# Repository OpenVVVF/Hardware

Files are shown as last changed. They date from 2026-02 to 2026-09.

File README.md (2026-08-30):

# OpenVVVF Hardware

> This repository contains the **OpenVVVF Hardware** designs. User-facing documentation, safety analyses, assembly guides, and test evidence now live in [OpenVVVF/Documentation](https://github.com/openvvvf/documentation) (rendered at https://docs.openvvvf.org/). The matching firmware, Real Time Examiner (RTE) host tool, and supporting configuration utilities (including node codegen and telemetry tooling) now live in [OpenVVVF/RTE](https://github.com/OpenVVVF/RTE).

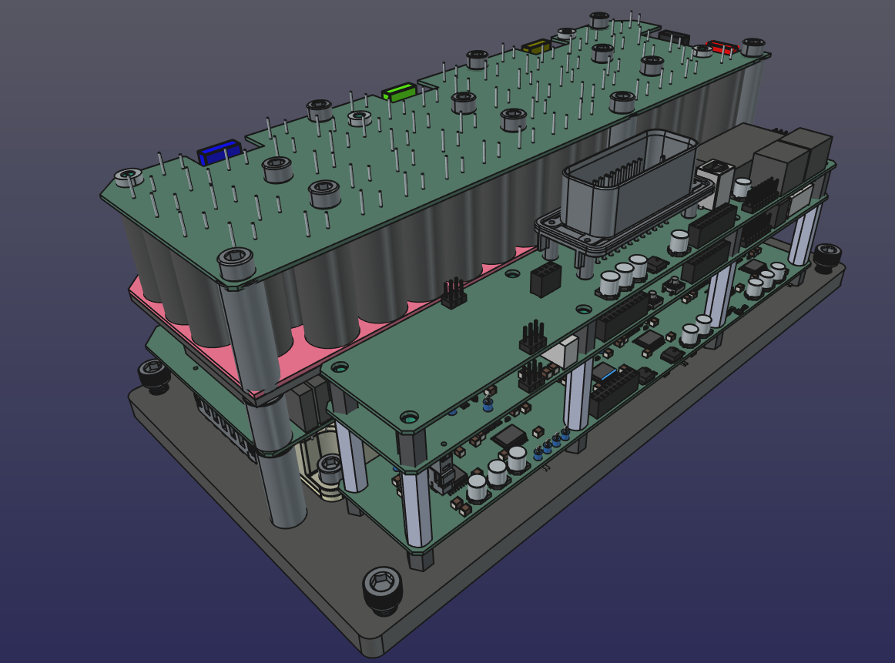
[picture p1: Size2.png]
Size 2 Inverter CAD Rendering


*Our current in-progress build photos for size 2 are below, thanks again to our sponsors for helping make this possible*
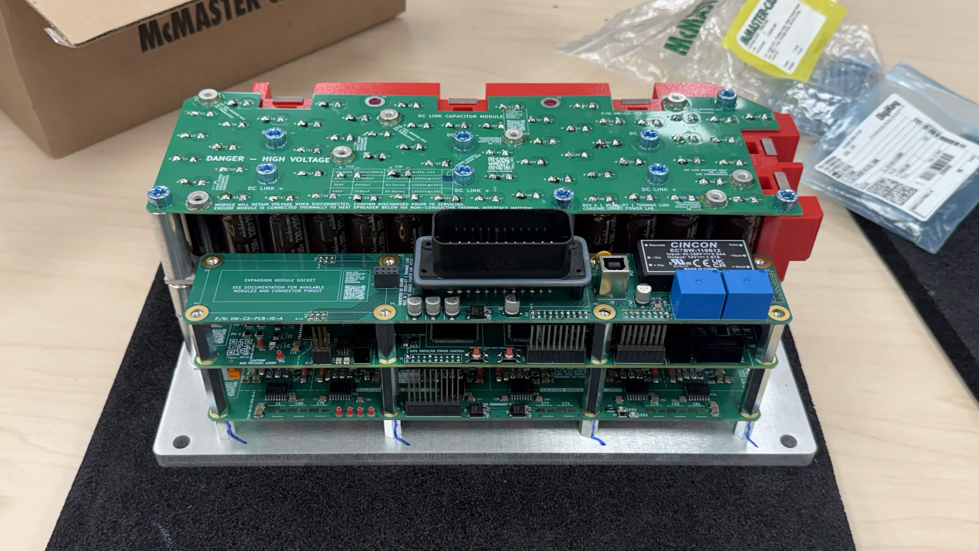
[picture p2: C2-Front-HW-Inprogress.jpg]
Size 2 Inverter Physical Assembly In-Progress

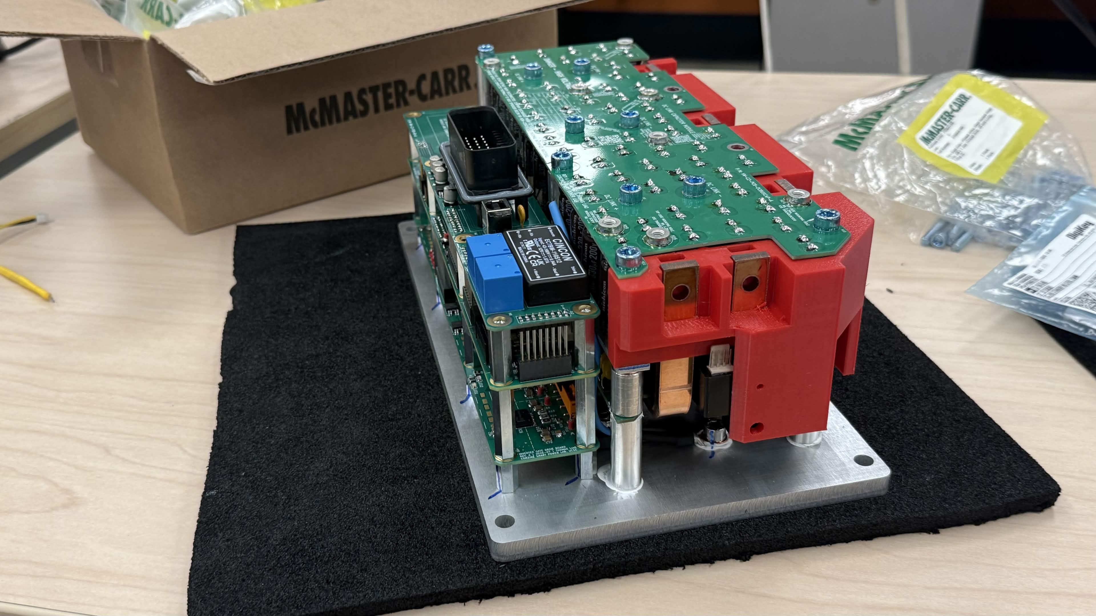
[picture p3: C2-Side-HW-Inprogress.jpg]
Size 2 Inverter Physical Assembly In-Progress


An open-source, high-power voltage-source inverter (VSI) for 3-phase AC drives. The design centres on a dual-MCU control board with an independent safety coprocessor, fully isolated gate drives and sensing, dual isolated CAN buses, and a control stack configurable through node-based codegen tools.

> **A note on the name:** *VVVF* stands for Variable Voltage Variable Frequency — it describes the output, not the control strategy. This platform is **not** limited to scalar V/Hz control; it supports vector control (FOC), arbitrary modulation schemes, and any control scheme you can express through the node-based codegen tools.

The present hardware implementation (Chassis Size 2) is a 200–450 V class build rated **465 A continuous / 600 A peak for 60 s** (IEC 61800-2 style overload convention; peak phase current figures — 330 A / 424 A RMS). The usable DC bus voltage is set by the installed DC link capacitors: 200 V class with the stock 200 V aluminium-electrolytic bank, or up to 450 V class with a capacitor-only swap to 450 V parts. The platform is designed to scale to higher voltage and current classes with appropriate gate-driver, DC link, and sensing-divider adaptations.

This project is currently being developed in Dr. Keith Corzine's Smart Power Lab at the University of California, Santa Cruz.

The hardware designs are modular and share a common control architecture and communication interfaces with the firmware in [OpenVVVF/RTE](https://github.com/OpenVVVF/RTE). All hardware and software are released under open-source licenses.

## Platform Scalability

The control board is designed as a reusable platform that is largely independent of the power stage. With isolation barriers rated for high-voltage power stages (CAN transceiver VIORM 2121 V<sub>PK</sub>; voltage-sense range 1.8 kV full-scale), the same inverter can be paired with a wide range of inverter classes; higher voltage classes are achievable with straightforward gate-driver and sensing-divider adaptations. The PWM and protection interfaces are also compatible with user-supplied gate-drive stages, allowing the inverter to be integrated into custom power-converter designs. Planned chassis variants include:

| Variant | Voltage Class | Phase Current | Status |
|---|---|---|---|
| Chassis Size 2 | 200 V class (stock 200 V capacitors); 450 V class (450 V capacitor swap) | 465 A continuous / 600 A peak, 60 s | Implemented, under test |
| Chassis Size 2 DC/DC module (C2-DCDC-A) | 450 V class | 15 kW DC/DC converter | Released (orderable BOMs) |
| Chassis Size 3 | Up to 1200 V (capacitor-dependent) | 1400 A | In development |

The **Chassis Size 2 DC/DC module** (release tag `C2-DCDC-A`) reuses the Chassis Size 2 PCBs and power stage as a 15 kW DC/DC converter for microgrid applications, built in the 450 V capacitor class. On top of the base machine it adds a pair of Hammond 195C100 DC filter chokes (1 mH, 100 A), two Boyd 416201U00000G 305 mm 6-pass cold plates, a TDK B25645A1328K003 3.21 mF/1 kV DC-link film capacitor, and a sheet-metal frame/cabinet set (base plates, cornerposts, cover lids, coldplate holder). The assembly model is `Hardware/Chassis2/Mechanical/DC-DC-Module.FCStd` (exported as `DC-DC-Module.step.gz`); the orderable BOMs, pricing report, and fab files are generated by the BOM tool as the `dcdc` build variant under `Hardware/Chassis2/FabricationData/Builds/dcdc/`.

Semiconductor ratings are selected with margin for the target DC bus: Chassis Size 2 uses 600 V rated IGBTs for the 200–450 V range, while future higher-voltage classes use 1200 V or 1700 V rated parts as appropriate.

## Hardware Architecture

### Power Stage
- **3-phase 2-level IGBT bridge** built from three Mitsubishi CM600DY half-bridge modules (six switches, 600 A class, 62 mm package). The recommended device for Chassis Size 2 is the **CM600DY-13T** (600 V), which matches the 200–450 V DC bus range. The **CM600DY-24T** (1200 V) is also electrically and mechanically compatible and may be used if a higher-voltage device is preferred.
- **Phase current**: 465 A continuous / 600 A peak for 60 s (peak phase current; 330 A / 424 A RMS) — continuous is a conservative analytical bound set by the DC-link electrolytic ripple rating at 6 kHz PWM (full-load dyno validation pending); peak duty is windowed: rolling 10-min RMS ≤ 330 A RMS
- **DC bus voltage**: 200–450 V class, set by the installed DC link capacitors — 200 V class with the stock bank, up to 450 V class with a capacitor-only swap (see DC Link below)
- **Gate drivers**: Six onsemi NCV57100 isolated IGBT gate drivers (one per switch, AEC-Q100 automotive-qualified)
  - Reinforced isolation: >5 kV<sub>rms</sub> (UL1577), 1424 V<sub>PK</sub> / 1000 V<sub>rms</sub> working voltage (VDE 0884-11)
  - DESAT short-circuit detection (1200 V fast-recovery diode + blanking) with soft turn-off
  - Separate OUTH/OUTL gate outputs; active Miller clamp connected directly to the gate
  - Complementary IN+/IN&minus; inputs cross-wired between the high- and low-side switches of each leg — hardware shoot-through lockout
  - All six ~FLT outputs wired-OR into a single FAULT net (&rarr; TIM1_BKIN); all six ~RDY wired-OR into a READY net; common DRIVER_RESET line
- **Gate drive power**: Six Murata MGJ2D121509MPC-R7 isolated DC/DC converters
  - 12 V input &rarr; isolated +15 V / &minus;9 V bipolar output per gate driver
  - Each supply fully isolated from logic and from each other
  - **1oo2 power kill**: the common 12 V feed passes through two series-connected BTS462T smart high-side switches — one controlled by the main MCU (GATE_DRIVE_PWR1_ENABLE), one by the coprocessor (GATE_DRIVE_PWR2_ENABLE). Either switch opening removes power from all six supplies simultaneously, forcing all IGBT gates off as the driver rails collapse into UVLO (gates discharge via the OUTL/Miller-clamp path). Resistor-divider feedback from both switch nodes (GATE_DRIVE_PWR1_FB / GATE_DRIVE_PWR2_FB) lets each MCU verify the other's path.
- **Power-stage agnostic control board**: The same inverter and firmware can be paired with alternative power stages with only gate-driver and sensing-divider scaling; higher voltage classes are achievable with straightforward adaptations, or the board can be interfaced to a user-supplied gate-drive stage.

### DC Link
- **Capacitor bank (current build)**: 60&times; Nichicon UCS2D331MHD 330 &micro;F / 200 V aluminium electrolytics in parallel &rarr; 19.8 mF total, 200 V class. The 450 V capacitor-only upgrade is a single part-number swap to 60&times; Nichicon UCS2W680MHD 68 &micro;F / 450 V parts (4.08 mF total); the only mechanical change is 5 mm shorter standoffs (e.g., 55 mm &rarr; 50 mm) to match the shorter capacitors. This is what gives Chassis Size 2 its 200–450 V class range.
- **Filter board**: 6&times; 10 &micro;F / 1000 V metallized polypropylene film capacitors (absorb high-frequency ripple and clamp switching voltage spikes, reducing RMS ripple current in the electrolytics) + 12&times; 0.25 &micro;F / 900 V TDK CeraLink low-inductance ceramics at the module terminals + 18&times; 2.2 nF class-Y safety capacitors to chassis for common-mode / bearing-current (EDM) suppression
- **Busbar-style construction**: all power connections are M6 bolted mounting holes; the mounting hardware sits at bus potential — observe high-voltage precautions during assembly
- **No onboard bleeder**: the bank has no discharge resistor and remains at bus voltage for hours after power-down (discharge only via M&Omega;-scale parasitic paths). Verify bus voltage with a meter and discharge through a power resistor before any service.
- **Capacitor cooling**: the capacitor bank is thermally coupled to a 6.35 mm (1/4 in) aluminium heat-spreader plate (rev B; thickened from 3.18 mm rev A), itself mounted to the heatsink via six 63 mm aluminium standoffs (13 mm OD, three go-return pairs in parallel - the rods also carry the DC-link current between the film board and the capacitor bank). The thermal path is sized for a 40 W ripple-current heat load: ~35 &deg;C total temperature rise with thermal paste (&asymp;75 &deg;C plate temperature at a 40 &deg;C heatsink base). Full analysis: [DC Link Thermal Analysis](https://openvvvf.github.io/Documentation/Power-Stages/C2/Design-Documents/DC-Link-Thermal/index.html) in OpenVVVF/Documentation. Use aluminium standoffs only — steel is not acceptable in this thermal path.
- **Precharge**: onboard high-side relay on the IO board with a user-supplied external resistor — size the resistor so precharge current stays below 2 A (input fuse limit)

### Current Sensing
- **Four Tamura LA37S600S05KM hall-effect current transducers** (3 phase + DC link)
  - &plusmn;1200 A sensing range, centered at 2.5 V output
  - Separate reference signal per sensor for fault detection
  - ~70 mA/LSB quantization at 16-bit (&asymp;300 mA effective resolution after oversampling/decimation); overall accuracy is dominated by the sensor's &plusmn;1.8% specification
  - Analog ground kept separate and bonded at the STM32 for noise reduction

### Voltage Sensing
- **MAX22530AWE+ 12-bit isolated ADC** with 4 channels
  - Measures DC bus voltage and all three phase voltages (U, V, W)
  - 1001:1 high-voltage divider per channel (4&times; 250 k&Omega; nominal series + 1 k&Omega; shunt, zener-clamped) &rarr; measurable range to ~1.8 kV full-scale, ~0.44 V/LSB referred to the bus (continuous bus limited to ~800 V by the fitted divider resistors; higher-voltage builds need HV-rated divider parts)
  - ~&plusmn;1 V measurement accuracy at the 140 V build with calibration (divider tolerance dominates at higher bus voltages)
  - SPI interface to STM32; isolation provided by the ADC's internal reinforced barrier

### Communication
- **Dual isolated CAN bus**: ISO1042BDWVR isolated CAN FD transceivers (70 V bus fault protection)
  - Two transceivers per bus (four total): the main MCU and the safety coprocessor each have an independent, galvanically isolated transceiver on both buses, so the coprocessor can snoop and cross-check all bus traffic
  - Per-bus isolated 5 V supply with firmware-switchable power; jumper-selectable 120 &Omega; termination
  - CAN1: Battery Management System (BMS) and IO board harness
  - CAN2: display/dash, charger(s), diagnostic tools
- **Expansion module connector (J2, IO board)**: plug-in expansion header carrying MD_FIBER_TX/RX/SYNC, +5 V, +12 V, and GND for future add-on modules. Planned modules include:
  - **Fiber IO multidrive module** — distributed-drive coordination for 5+ phase motors, parallel power stages with current sharing and load balancing, or tightly synchronized multi-drive systems with hardware PWM sync between drives
  - **Fiber-optic gate-drive module** — isolated PWM signaling directly to gate drivers
  - **WiFi/Bluetooth module** — wireless telemetry and configuration
  - **Resolver interface module** — resolver position feedback (native inputs support sin/cos encoder or Hall effect only)
- **BMS heartbeat**: 5-second timeout (HARA FSR-17; BMS external to this system; firmware implementation in progress)

### Control Electronics — Dual-MCU Architecture
- **STM32H723ZG** main MCU (550 MHz Cortex-M7)
  - ECC-protected RAM, 1 MB flash
  - FDCAN1 + FDCAN2, TIM1 advanced-control PWM, 16-bit ADCs
  - Runs FOC motor control, sensor acquisition, CAN communication, safe state management
  - GATE_DRIVE_PWR1_ENABLE — gate drive power kill Path 2a
  - CY15B102Q-SXET 256 KB SPI FRAM (GPIO-controlled write-protect) for fault logs, configuration, hour meter, odometer
- **STM32G474RCTx** safety coprocessor (170 MHz Cortex-M4+FPU)
  - 8 MHz crystal; powered from the shared 3.3 V rail (dedicated RD7-12S033R DC/DC converter)
  - FDCAN2 + FDCAN3 (independent transceivers on both CAN buses for snooping/cross-check)
  - Independent ADC access to all current sensors, temperatures, encoder, gate drive feedback
  - Monitors all 6 PWM output pairs (high/low) for deadtime violations, stuck-on, stuck-off
  - GATE_DRIVE_PWR2_ENABLE — gate drive power kill Path 2b (1oo2 with main MCU)
  - Challenge-response watchdog with main MCU via inter-MCU UART
  - Bidirectional NRST and mutual BOOT0 control — either MCU can reset or bootloader-force the other; own SWD and native USB debug ports
- **Rail supervision**: TI TPS389006-Q1 6-channel window supervisor with I2C-programmable thresholds (TI Functional Safety-Compliant component, supporting designs up to SIL 3 / ASIL D per TI)
  - Monitors the 3.3 V, 5 V, 12 V, and sensor 5 V rails plus both gate-drive power feedbacks; thresholds are I2C-configured by the main MCU at boot
  - On any rail fault — including brownout of the 3.3 V rail shared by both MCUs — it asserts DRIVER_RESET **directly**, forcing all NCV57100 outputs off while bypassing both MCUs. The actuation path is hardware-only: an independent mitigation for the shared-rail common-cause failure mode
- **Isolated digital inputs**: 8&times; ISO1212 24&ndash;60 V isolated input channels (2 populated in the current build, routed to the coprocessor) for e-stop, limit switches, and user inputs
- **Onboard power**: Cincon EC7BW-110S12 railway-grade DC/DC (mounted on the IO board, powered from the traction battery)
  - 43&ndash;160 V input (4:1), 12 V / 1.67 A output
  - EN 50155 compliant with external circuitry (per Cincon application note), 1500 V I/O isolation
  - Control-board rails derived from 12 V: 3.3 V (RD7-12S033R), isolated 5 V (RKE-1205S), firmware-switched 12 V aux and CAN-bus power (BTS462T high-side switches)
- **Fail-safe default**: Six-switch-open (SSO) &mdash; all IGBTs off

### Throttle Input
- Dual redundant 5 k&Omega; potentiometers + end-travel limit switch (via isolated digital input)
- 0&ndash;5 V output scaled to 0&ndash;3.3 V via resistor dividers
- Both MCUs read throttle independently; discrepancy &gt;5% triggers safe state

### Safe State Entry — Six Redundant SSO Pathways

1. **TIM1_BKIN hardware break input to main MCU** (<100 ns) — OR'd gate driver FLT → hardware clears MOE, all PWM disabled
2. **Coprocessor reset to main MCU via NRST** (~100 ms) — challenge/response failure → coprocessor resets main MCU → SSO during boot
3. **Loss of shared 3.3 V rail (passive)** — NCV57100 VDD lost → internal active pull-down → SSO; no software intervention
4. **Gate driver RESET line** (<1 us actuation once asserted, either MCU or the TPS389006-Q1 rail supervisor) — asserts DRIVER_RESET → all NCV57100 outputs off → SSO
5. **1oo2 gate-drive power disable** — main MCU (`GATE_DRIVE_PWR1_ENABLE`) or coprocessor (`GATE_DRIVE_PWR2_ENABLE`) opens its BTS462T; either alone removes 12 V → gate-drive UVLO → SSO. Feedbacks: `GATE_DRIVE_PWR1_FB`, `GATE_DRIVE_PWR2_FB`
6. **Coprocessor independent fault trigger** (<10 us) — coprocessor detects critical fault → `GATE_DRIVE_PWR2_ENABLE` low + RESET → SSO without main MCU

> **Note:** HARA v4.1 numbers these as Path 1, Path 5, Path 3, Path 4, Paths 2a/2b, and Path 6, respectively. The TPS389006-Q1 rail supervisor is an additional actuator on the RESET pathway (Path 4), not a separate SSO path.

### Safety Protections (Hardware + Dual-MCU)

*Hardware for all mechanisms below is in place; firmware implementation of several monitors is in progress (see Project Status).*

- Hardware PWM disable via TIM1_BKIN (&lt;100 ns)
- NCV57100 DESAT short-circuit protection (&lt;2 us)
- 1oo2 gate drive power kill with independent feedback (GATE_DRIVE_PWR1_FB, GATE_DRIVE_PWR2_FB)
- TPS389006-Q1 rail supervisor (Functional Safety-Compliant, up to SIL 3 / ASIL D per TI) — resets the gate drivers directly on brownout, independent of both MCUs
- Dual independent watchdog timers (main MCU windowed WDT + coprocessor challenge/response)
- HVIL (High-Voltage Interlock Loop) presence signalling &mdash; planned (TODO on IO board schematic)
- All six NCV57100 FLT outputs OR'd — monitored by **both** MCUs
- Overcurrent detection: ADC analog watchdogs in both MCUs (hardware threshold monitoring, no external comparators) + dual-MCU integrated monitoring — detection within 100 ms for regular overcurrent; SSO assertion within 1 PWM period (~100 µs) once detected — sufficient for safe torque off without hardware damage (DESAT handles hard shorts &lt;2 us) + Analog watchdog on main processor and coprocessor for overcurrent.
- **Target: ASIL D** via ASIL B(D) + ASIL B(D) decomposition (DFA per ISO 26262-9 pending — LIMIT-08)

> **Note on Overcurrent Protection:** Hardware overcurrent detection uses the ADC analog watchdogs built into both STM32s — comparator-equivalent threshold monitoring on each current channel with no external components. The control board also includes schematic provision for LM397 comparators for phase and DC link overcurrent detection, but these are not populated in the current build and are not required for the safety case. Hard short-circuits are handled by NCV57100 DESAT (&lt;2 us). Regular overcurrent (non-DESAT) is detected within **100 ms** by dual-MCU integrated monitoring and AWD — both the STM32H723 and STM32G474 independently sample all current channels at high rate. Once detected, either MCU asserts SSO within **1 PWM period (~100 µs)** via its independent gate drive power kill — the full sense-to-safe-off path. The 100 ms detection latency is faster than the IGBT thermal time constant; junction temperature remains within module ratings for overloads sustained up to the 100 ms detection bound. The LM397 provision is retained in schematic, and may be removed in future versions pending testing and validation of current design.

## Motor Control

Field-Oriented Control (FOC) running at PWM switching frequency with the following modulation strategies:
- **SPWM** &mdash; Sinusoidal Pulse Width Modulation
- **SVPWM** &mdash; Space Vector Modulation
- **ARSVPWM** &mdash; Alternating Reverse Sequence Vector PWM
- **SHEPWM** &mdash; Selective Harmonic Elimination
- **RCFM** &mdash; Random Carrier Frequency Modulation
- **RSPWM** &mdash; Random Sinusoidal PWM
- **N-Pulse / N-Pulse Wide / N-Pulse Custom** &mdash; Low pulse-count for high-speed operation
- **RSVM** &mdash; Random Space Vector Modulation

SPWM and SVPWM are implemented in the current firmware in [OpenVVVF/RTE](https://github.com/OpenVVVF/RTE); the remaining schemes are architected and in development (see Project Status). The modulation framework is designed for live scheme switching via CAN bus, automatic selection based on speed/torque operating region with configurable hysteresis to prevent boundary jitter, and bumpless crossfade with di/dt gating during regen/acceleration transitions (framework features in development — see Project Status). All configurable via the Real Time Examiner (RTE) interface tool in OpenVVVF/RTE, which also hosts node codegen, telemetry, and other configuration utilities.

**Model Predictive Control (MPC)** is a planned addition to the control strategy set.

## Functional Safety

All safety documentation, user manuals, assembly guides, and software docs are maintained in [OpenVVVF/Documentation](https://docs.openvvvf.org/) (rendered at https://openvvvf.github.io/Documentation/).

**Important:** ASIL ratings are targets derived from the HARA process, not compliance claims. The dual-MCU architecture (STM32H723 + STM32G474 coprocessor) enables ASIL D for SG-01 and SG-13 via ASIL B(D) + ASIL B(D) decomposition. No formal ISO 26262 compliance audit has been performed. A Dependent Failure Analysis (DFA) per ISO 26262-9 is required before formal ASIL D claims can be substantiated — this is documented as the remaining P0 gap (LIMIT-08). This is a design-for-safety effort. Security follows a **user sovereignty** model: the project explicitly rejects anti-user OTP/DRM measures (no vendor lock-in, no encrypted bootloaders with unreplaceable keys). Protections target remote CAN bus attacks, not the legitimate hardware owner. Physical access = user is root.

## Project Status

### Hardware
| Milestone | Status |
|---|---|
| Main inverter schematic and PCB design | Complete |
| STM32 prototype assembly | Complete, under active test |
| FOC current-loop bench validation (±50 A Iq on Zero 75-10, 50 V bus, no heatsink/airflow, baseplate barely warm) | Complete |
| Voltage/current bring-up and longer-load bench testing | In progress — 100 V / 60 A continuous for 10 min and ±200 A Iq reversal for ~1 min survived on Zero 75-10; heatsink estimated ~70–85 °C with no airflow or heatsink; 400 A trial paused due to on-site power supply limitations, motor phase cables melting, and lorentz force moving phase leads > 4cm |
| 200 V-class variant bench test (120 V, 20 min, no heatsink) | Complete — heatspreader plate reached 41.6 °C measured by thermal camera |
| Full-load dyno testing (motor coupled) | Planned |
| Environmental and thermal validation | Planned |

> **Note:** All high-current runs so far have been without a proper heatsink, forced airflow, or temp probes; temperatures are estimates. Proper thermal validation with temp sensors is planned in the next few days.

### Software/Firmware
| Milestone | Status |
|---|---|
| Real Time Examiner (RTE) host tool | In development in [OpenVVVF/RTE](https://github.com/OpenVVVF/RTE), which also includes node codegen and telemetry tools |
| STM32 low-level drivers (ADC, PWM, CAN, GPIO) | Implemented and tested |
| Communication protocol | Implemented |
| Sensor acquisition and filtering | Implemented |
| Field-Oriented Control (FOC) | Current loop implemented and validated at ±50 A Iq on Zero 75-10 (50 V bus, no heatsink/airflow); speed/torque loop in development |
| Torque command processing and safety limits | Architecture defined, implementation in progress |
| Fault handling and safe state management | Architecture defined, implementation in progress |
| Power-on self-test (POST) | Architecture defined |

### Safety Analysis
| Deliverable | Status |
|---|---|
| HARA &mdash; Unified (Rev. 4.1, dual-MCU) | Complete |
| TARA &mdash; Threat Analysis (Rev. 1.2, anti-OTP/user-sovereignty) | Complete |
| SWAD &mdash; Software Architecture (Rev. 1.5, dual-MCU body update planned) | Complete |
| Technical Safety Concept | Not started |
| Component-level FMEA | Not started |
| Fault injection test plan | Complete (99 tests defined) |

## Getting Started

### For Users

The BOM, Gerbers, and manufacturing files are in the `Hardware/Chassis2/` directory. Assembly is recommended for experienced builders only. This design involves high voltages (200–450 V class depending on the installed DC link capacitors; higher voltage classes require a different chassis/power-stage design) and currents (up to 600 A) that can be lethal. The DC link bank has no onboard bleeder and stays at bus voltage for hours after power-down. An active discharge command (using the motor windings as a bleeder resistor) is planned but not yet implemented — until then, always verify with a meter and discharge through a power resistor before service. Proper safety equipment and procedures are mandatory.

**Prerequisites:**
- Compatible battery pack (43&ndash;160 V for the current build's onboard supply; higher bus voltages require appropriate DC link capacitors and supply adaptation)
- 3-phase PMSM motor with sin/cos encoder or Hall effect position feedback
- Compatible BMS with CAN communication
- 12 V auxiliary supply (or self-powered via onboard DC/DC)
- Direct CAN interface for configuration (RTE host tool in development in [OpenVVVF/RTE](https://github.com/OpenVVVF/RTE) — includes node codegen and telemetry tools)

### For Contributors

Contributions are welcome. This project uses **KiCad** for schematic and PCB design, **FreeCAD** for mechanical design, and **STM32CubeIDE / GCC ARM** for firmware (now developed in [OpenVVVF/RTE](https://github.com/OpenVVVF/RTE)).

When contributing:
- Maintain consistency with existing design conventions
- Include schematics, PCB layouts, BOMs, and documentation
- Reference relevant Safety Goals when modifying safety-critical code or hardware
- Update the HARA if your change affects hazard controls

## License

Hardware designs are released under the **CERN Open Hardware Licence**.

Safety documentation is provided for reference and design guidance purposes.

## Sponsors

A special thank you to our sponsors, **[Mouser Electronics](https://mouser.com)**, **[Mitsubishi Electric](https://www.mitsubishielectric.com/semiconductors/powerdevices/)**, and **[SendCutSend](https://sendcutsend.com/)**! Their support has been invaluable for making this project possible.

---

*This project involves high voltages and currents that can cause serious injury or death. Do not attempt to build, test, or operate this equipment without proper training, safety equipment, and procedures. The authors and contributors accept no liability for any injury, damage, or loss resulting from the use of this design.*

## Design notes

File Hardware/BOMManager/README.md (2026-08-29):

# BOM Manager

Your fab-time companion for the inverter build. It aggregates the Bill of
Materials from KiCad PCB exports, wiring-harness schematics, mechanical
hardware, and custom fabricated parts — then helps you price everything,
order the right quantities (including pack sizes and what is already on your
shelf), and keep fabrication packages ready to send out.

## The interactive shell

```bash
cd Hardware/BOMManager
python3 bom.py
```

```
bom> status                     # where you stand: lines, prices, attention items, fab readiness
bom> mech                       # the MechanicalBOM.txt hardware list (the tool owns this file)
bom> mech add McMaster 94669A199 12 M3x10 SHCS
bom> price 94669A199 3.10       # set a price (per piece, or per pack if packed)
bom> pack 94669A199 25          # sold in boxes of 25 -> ordering does the math
bom> stock 94669A199 19         # 19 left over on your shelf (stays local, never committed)
bom> add                        # walk through BOM lines that still need vendor PNs/prices
bom> new fab Phase Bus Bar      # scaffold a fabricated-part folder (+README)
bom> new harness GateDriverHarness
bom> new board PowerBoard
bom> rev bump DCLBB --note "widen holes"
bom> fab                        # fabrication package readiness: PCBs, fab parts, harnesses
bom> import mouser              # paste a cart/order, prices land in cache AND the committed DB
bom> import digikey ~/Downloads/digikey_bom.csv.xlsx
bom> release                    # order files + full PDF report (schematics, layers, pricing)
```

Every command also works one-shot for scripting: `python3 bom.py generate --qty 5`.
Type `help` inside the shell for the full list. **See `docs/GUIDE.md` for the
complete usage guide.**

The old scripts (`generate_bom.py`, `manage_parts.py`, `import_*.py`) still run
— they are thin shims that delegate to the shell.

## What `generate` and `release` produce

Per chassis, under `Hardware/<Chassis>/FabricationData/`:

```text
├── BOMs/
│   ├── Consolidated_BOM.csv     # everything, with Order Qty / Pack Size / Leftover columns
│   ├── mouser_bom.csv           # upload to the vendor's BOM tool
│   ├── digikey_bom.csv
│   ├── mcmaster_bom.csv
│   ├── sendcutsend_bom.csv
│   ├── pcb_bom.csv
│   └── assembly_bom.csv         # in-house assemblies (wiring harnesses)
├── McMaster_Order_Paste.txt     # paste straight into the McMaster cart
├── PCB_Fab_Zips/<Board>.zip     # per-board fab bundles
├── Assembly/<Board>.html        # interactive assembly view per board (iBOM; via release)
├── Pricing_Report.md            # costs, pack rounding, fabrication package checklist
├── Release_Report.pdf           # full release doc (HARA-style; via release): cover, pricing,
│                                # STEP previews, per-board 3D renders + schematic + layers
├── Builds/<variant>/            # build-variant outputs, when variants.yaml declares them
│                                # (same file set as above; the default variant stays at this root)
├── Variant_Comparison.md        # per-variant totals + part deltas (tracked)
└── variants.json                # machine-readable variant manifest (tracked)
```

Chassis with a `variants.yaml` (e.g. Chassis2's 200v/450v builds) generate all
declared build variants at once; `generate --variant 450v` builds a subset. See
[docs/GUIDE.md](docs/GUIDE.md#build-variants) for the schema.

## How ordering math works

- A part with `pack_size = 25` and 6 needed → order **1 pack**, 19 left over.
- `stock` counts are subtracted first: 6 needed, 19 on hand → order 0.
- Order quantities (packs) are what land in vendor CSVs and the McMaster paste
  file; lines fully covered by stock are skipped there but still shown in the
  Consolidated BOM and the report's **Pack Rounding & Stock** section.
- Prices are per **order unit**: per piece normally, per pack when packed.

## Where data lives

Committed (project data, diff-friendly):

| File | Contents |
|---|---|
| `bom_manager/data/part_database.json` | vendor PNs, pack sizes, manual prices, notes |
| `bom_manager/data/part_numbers.json` | internal PN registry with revision history |
| `bom_manager/data/part_descriptors.json` | short names used in part numbers |
| `Hardware/<Chassis>/Mechanical/MechanicalBOM.txt` | purchased hardware list (edit via `mech` commands) |
| `Hardware/<Chassis>/Mechanical/Fab/<Part>/` | fabricated parts: STEP + `info.txt` + image |
| `Hardware/<Chassis>/Wiring/<Name>/` | wiring harnesses: KiCad schematic + BOM CSV export |

Local only (gitignored): `config.yaml` (API keys), `price_cache.json`,
`inventory.json` (your on-hand stock — your leftover screws are not project data).

## Part numbers and revisions

Every BOM line gets an internal PN like `HW-C2-BB-DCLBB-A`
(chassis, category, descriptor, revision). Registry keys are **identity-based**,
so editing a description or friendly part name never renumbers anything, and
folder names never need to change for a revision:

```text
bom> rev list
bom> rev bump DCLBB --note "widen mounting holes"
```

For fabricated parts this writes `Rev=B` into the part's `info.txt` — the
folder and STEP file stay put, so CAD and vendor links keep working.

## First-time setup

```bash
pip install -r requirements.txt        # runtime deps
pip install -r requirements-dev.txt    # + pytest, for the test suite
python3 -m pytest tests/               # sanity check
cp config.yaml.example config.yaml     # optional: vendor API keys (docs/API_KEYS.md)
```

API keys are optional — the whole workflow runs on manual prices and pasted
cart/order imports.

## Docs

- `docs/GUIDE.md` — **complete usage guide (start here)**
- `docs/WORKFLOW.md` — end-to-end fab-time walkthrough
- `docs/CUSTOM_PARTS.md` — fabricated parts and SendCutSend
- `docs/PART_NUMBERING.md` — internal PN conventions and revisions
- `docs/API_KEYS.md` — optional vendor API setup
- `docs/SPARES_AND_REPORTING.md` — spares policies and report format

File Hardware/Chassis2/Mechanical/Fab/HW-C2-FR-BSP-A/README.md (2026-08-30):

# HW-C2-FR-BSP-A — Chassis Frame Base Plate

Bent 3 mm 5052 aluminium base plate with mounting flanges for the DC/DC
converter module frame. Qty 2 per module (left/right pair). Order per
`fab_spec.yaml`; geometry in `HW-C2-FR-BSP-A.step` (source body lives in
`../../DC-DC-Module.FCStd`, `Chassis-Frame` subassembly).

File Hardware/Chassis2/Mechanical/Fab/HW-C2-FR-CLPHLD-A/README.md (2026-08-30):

# HW-C2-FR-CLPHLD-A — Front Coldplate Holder Bracket

Bent 3 mm 5052 aluminium bracket that carries the two Boyd 416201U00000G
coldplates at the front of the C2 DC/DC converter module. Order per
`fab_spec.yaml`; geometry in `HW-C2-FR-CLPHLD-A.step` (flat pattern source is
the `HW-C2-FR-CLPHLD-A` body in `../../DC-DC-Module.FCStd`).

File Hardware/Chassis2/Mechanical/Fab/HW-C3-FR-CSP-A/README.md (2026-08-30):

# HW-C3-FR-CSP-A — Chassis Cornerpost

Bent 3 mm 5052 aluminium angle cornerpost for the DC/DC converter module
frame. Qty 4 per module; the hex-punched holes take McMaster 90720A550 rivet
nuts (pressed in after fab, 2 per post). Shares geometry with the Chassis 3
front frame (source body in `../../DC-DC-Module.FCStd`, `Chassis-Frame` >
`Chassis-Cornerpost`).

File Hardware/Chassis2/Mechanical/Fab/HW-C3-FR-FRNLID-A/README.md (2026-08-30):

# HW-C3-FR-FRNLID-A — Front Cover Lid

Bent 3 mm 5052 aluminium front cover lid for the DC/DC converter module
frame. Qty 2 per module, retained by 6x 90166A718 flanged hex screws each.
Shares geometry with the Chassis 3 cabinet cover (source body in
`Cabinet-Cover-410mm.FCStd`, linked from `../../DC-DC-Module.FCStd`).

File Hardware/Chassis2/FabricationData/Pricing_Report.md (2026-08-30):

# Hardware BOM Pricing Report

Generated: 2026-08-30T06:47:26.650992Z

Base quantity: 1 unit(s)

---

## In-House Assembly

| Qty | Order | Internal P/N | Description | Part Number | Unit Price | Line Total | Source |
|-----|---|---|---|---|---|---|---|
| 1 |  | HW-C2-WH-TSBCM-A | CapacitorTempSenseHarness |  | N/A | N/A | manual |
| 4 |  | HW-C2-WH-CS-A | CurrentSenseHarness |  | N/A | N/A | manual |
| 1 |  | HW-C2-WH-GDVS-A | GDVSHarness |  | N/A | N/A | manual |
| 2 |  | HW-C2-WH-TSIGBT-A | TempSenseHarness |  | N/A | N/A | manual |

**In-House Assembly subtotal:** $0.00

## McMaster-Carr

| Qty | Order | Internal P/N | Description | Part Number | Unit Price | Line Total | Source |
|-----|---|---|---|---|---|---|---|
| 1 |  | HW-C2-MECH-1821A55-A | 1821A55 | 1821A55 | N/A | N/A | mcmaster_scrape |
| 8 |  | HW-C2-MECH-6926K352-A | 6926K352 | 6926K352 | N/A | N/A | mcmaster_scrape |
| 5 |  | HW-C2-MECH-6926K56-A | 6926K56 | 6926K56 | N/A | N/A | mcmaster_scrape |
| 1 |  | HW-C2-MECH-7381K23-A | 7381K23 | 7381K23 | N/A | N/A | mcmaster_scrape |
| 8 | 1 pack x 100 (left 92) | HW-C2-MECH-90128A232-A | 90128A232 | 90128A232 | N/A | N/A | mcmaster_scrape |
| 5 | 1 pack x 50 (left 45) | HW-C2-MECH-90225A102-A | 90225A102 | 90225A102 | N/A | N/A | mcmaster_scrape |
| 4 |  | HW-C2-MECH-91292A108-A | 91292A108 | 91292A108 | N/A | N/A | mcmaster_scrape |
| 18 | 1 pack x 50 (left 32) | HW-C2-MECH-91292A134-A | 91292A134 | 91292A134 | N/A | N/A | mcmaster_scrape |
| 1 |  | HW-C2-MECH-91458A112-A | 91458A112 | 91458A112 | N/A | N/A | mcmaster_scrape |
| 6 | 1 pack x 25 (left 19) | HW-C2-MECH-91502A180-A | 91502A180 | 91502A180 | N/A | N/A | mcmaster_scrape |
| 6 | 1 pack x 10 (left 4) | HW-C2-MECH-91502A183-A | 91502A183 | 91502A183 | N/A | N/A | mcmaster_scrape |
| 4 |  | HW-C2-MECH-92125A228-A | 92125A228 | 92125A228 | N/A | N/A | mcmaster_scrape |
| 4 |  | HW-C2-MECH-94180A351-A | 94180A351 | 94180A351 | N/A | N/A | mcmaster_scrape |
| 6 |  | HW-C2-MECH-94669A190-A | 94669A190 | 94669A190 | N/A | N/A | mcmaster_scrape |
| 6 |  | HW-C2-MECH-94669A196-A | 94669A196 | 94669A196 | N/A | N/A | mcmaster_scrape |
| 12 |  | HW-C2-MECH-94669A199-A | 94669A199 | 94669A199 | N/A | N/A | mcmaster_scrape |
| 12 |  | HW-C2-MECH-96738A257-A | 96738A257 | 96738A257 | N/A | N/A | mcmaster_scrape |
| 25 | 1 pack x 25 (left 0) | HW-C2-MECH-98044A224-A | 98044A224 | 98044A224 | N/A | N/A | mcmaster_scrape |

**McMaster-Carr subtotal:** $0.00

## Mouser

| Qty | Order | Internal P/N | Description | Part Number | Unit Price | Line Total | Source |
|-----|---|---|---|---|---|---|---|
| 70 |  | HW-C2-CAP-100N-A | 100nF 100V | 80-C1210C104K1RAC | $0.1610 | $11.27 | manual |
| 21 |  | HW-C2-CAP-10N-A | 10nF 500V | 187-CL32B103KGFNNNE | $0.1430 | $3.00 | manual |
| 37 |  | HW-C2-CAP-10U-A | 10uF 25V | 187-CL32A106KAULNNE | $0.1340 | $4.96 | manual |
| 8 |  | HW-C2-CAP-1U-A | 1uf 50V | 187-CL32B105KBHNNNE | $0.2400 | $1.92 | manual |
| 2 |  | HW-C2-CAP-2U2-A | 2.2uf 1210 100v | 80-C1210C225J1RAUTO | $0.5200 | $1.04 | manual |
| 6 |  | HW-C2-CAP-220P-A | 220pF 100V C0G 1210 | 80-C1210C221J2G | $0.8800 | $5.28 | manual |
| 4 |  | HW-C2-CAP-22P-A | 22pF 50V | 80-C1210C220J5G | $0.7400 | $2.96 | manual |
| 2 |  | HW-C2-IC-8MHZ-A | 8mhz hc49-4h crystal | 710-830003156B | $0.5000 | $1.00 | manual |
| 1 |  | HW-C2-IC-CY15B102Q-SXET-A | CY15B102Q-SXET | 727-CY15B102Q-SXET | $18.1400 | $18.14 | manual |
| 4 |  | HW-C2-IC-ISO1042BDWVR-A | ISO1042BDWVR | 595-ISO1042BDWVR | $4.4400 | $17.76 | manual |
| 1 |  | HW-C2-IC-ISO1212DBQ-A | ISO1212DBQ | 595-ISO1212DBQ | $1.7300 | $1.73 | manual |
| 1 |  | HW-C2-IC-MAX22530AWE-A | MAX22530AWE+ | 700-MAX22530AWE+ | $15.6000 | $15.60 | manual |
| 6 |  | HW-C2-IC-NCV57100DWR2G-A | NCV57100DWR2G | 863-NCV57100DWR2G | $2.9800 | $17.88 | manual |
| 1 |  | HW-C2-IC-STM32G474RCT3-A | STM32G474RCT3 | 511-STM32G474RCT3 | $8.3100 | $8.31 | manual |
| 1 |  | HW-C2-IC-STM32H723ZGT6-A | STM32H723ZGT6 | 511-STM32H723ZGT6 | $13.2500 | $13.25 | manual |
| 1 |  | HW-C2-CONN-SSW-110-01-F-D-A | SSW-110-01-F-D | 200-SSW11001FD | $2.4100 | $2.41 | manual |
| 1 |  | HW-C2-CONN-TSW-110-21-L-D-LL-A | TSW-110-21-L-D-LL | 200-TSW11021LDLL | $2.2700 | $2.27 | manual |
| 8 |  | HW-C2-HW-0022011042-A | 0022011042 |  | N/A | N/A | manual |
| 32 |  | HW-C2-HW-08-50-0113-A | 08-50-0113 |  | N/A | N/A | manual |
| 4 |  | HW-C2-HW-22-04-1041-A | 22-04-1041 | 538-22-04-1041 | $0.8900 | $3.56 | manual |
| 3 |  | HW-C2-HW-455-2266-ND-A | 455-2266-ND | 306-XHP-2 | $0.1000 | $0.30 | manual |
| 25 |  | HW-C2-HW-464762-E-A | 464762-E | 305-464762 | $0.3970 | $9.93 | manual |
| 5 |  | HW-C2-HW-524265-E-A | 524265-E | 305-524265-E | $7.8700 | $39.35 | manual |
| 5 |  | HW-C2-HW-544959-E-A | 544959-E |  | N/A | N/A | manual |
| 1 |  | HW-C2-HW-776231-1-A | 776231-1 | 571-776231-1 | $16.6900 | $16.69 | manual |
| 1 |  | HW-C2-HW-951-GP1500-080-02-A | 951-GP1500-080-02 | 951-GP1500-080-02 | N/A | N/A | unknown |
| 8 |  | HW-C2-HW-971150581-A | 971150581 | 710-971150581 | $0.6000 | $4.80 | manual |
| 8 |  | HW-C2-HW-971250581-A | 971250581 | 710-971250581 | $1.1000 | $8.80 | manual |
| 8 |  | HW-C2-HW-971350581-A | 971350581 | 710-971350581 | $1.4800 | $11.84 | manual |
| 8 |  | HW-C2-HW-9774030592R-A | 9774030592R | 710-9774030592R | $1.5700 | $12.56 | manual |
| 2 |  | HW-C2-HW-ACT45B-101-2P-TL003-A | ACT45B-101-2P-TL003 | 810-ACT45B1012PTL003 | $1.5300 | $3.06 | manual |
| 2 |  | HW-C2-HW-AWHSH105D00G-A | AWHSH105D00G | 523-AWHSH105D00G | $1.1100 | $2.22 | manual |
| 3 |  | HW-C2-HW-B2B-XH-AM_LF__SN_-A | B2B-XH-AM_LF__SN_ | 306-B2B-XH-AMLFSNP | $0.1000 | $0.30 | manual |
| 12 |  | HW-C2-HW-B58031U9254M062-A | B58031U9254M062 | 871-B58031U9254M062 | $4.6500 | $55.80 | manual |
| 12 |  | HW-C2-HW-BAT54WS-7-F-A | BAT54WS-7-F | 621-BAT54WS-F | $0.1240 | $1.49 | manual |
| 5 |  | HW-C2-HW-BTS462TATMA1-A | BTS462TATMA1 | 726-BTS462TATMA1 | $2.6600 | $13.30 | manual |
| 3 |  | HW-C2-HW-CM600DY-24T-A | CM600DY-24T (CM600DY-13T recommended for Chassis Size 2 200-450 V; 24T also compatible) | CM600DY-24T | $323.5000 | $970.50 | manual |
| 1 |  | HW-C2-HW-DRDNB21D-7-A | DRDNB21D-7 | 621-DRDNB21D-7 | $0.5600 | $0.56 | manual |
| 1 |  | HW-C2-HW-EC7BW-110S12-A | EC7BW-110S12 | 418-EC7BW-110S12 | $48.8600 | $48.86 | manual |
| 12 |  | HW-C2-HW-FDFNYD1-110-5-A | FDFNYD1-110(5) | 161-FDFNYD1-1105 | $0.4800 | $5.76 | manual |
| 4 |  | HW-C2-HW-LA37S600S05KM-A | LA37S600S05KM | 838-LA37S600S05KM | $19.9600 | $79.84 | manual |
| 1 |  | HW-C2-HW-LT3080IQ-PBF-A | LT3080IQ#PBF | 584-LT3080IQ#PBF | $8.5400 | $8.54 | manual |
| 2 |  | HW-C2-HW-LTST-C230CKT-A | LTST-C230CKT | 859-LTST-C230CKT | $0.4100 | $0.82 | manual |
| 2 |  | HW-C2-HW-LTST-C230GKT-A | LTST-C230GKT | 859-LTST-C230GKT | $0.3600 | $0.72 | manual |
| 1 |  | HW-C2-HW-MF-RHT200_32-2-A | MF-RHT200_32-2 | 652-MF-RHT200/32-2 | $0.6100 | $0.61 | manual |
| 6 |  | HW-C2-HW-MGJ2D121509MPC-R7-A | MGJ2D121509MPC-R7 | 580-MGJ2D121509MPCR7 | $6.7700 | $40.62 | manual |
| 6 |  | HW-C2-HW-MKP1848S61010JY5B-A | MKP1848S61010JY5B | 75-MKP1848S61010JY5B | $7.5400 | $45.24 | manual |
| 5 |  | HW-C2-HW-MM3Z3V0ST1G-A | MM3Z3V0ST1G | 863-MM3Z3V0ST1G | $0.1700 | $0.85 | manual |
| 1 |  | HW-C2-HW-NXFT15XH103FEAB021-A | NXFT15XH103FEAB021 | 81-NXFT15XH103FEAB21 | $0.3400 | $0.34 | manual |
| 1 |  | HW-C2-HW-RD7-12S033R-A | RD7-12S033R | 737-RD7-12S033R | $6.7700 | $6.77 | manual |
| 3 |  | HW-C2-HW-RKE-1205S_H-A | RKE-1205S_H | 919-RKE-1205S/H | $5.1700 | $15.51 | manual |
| 2 |  | HW-C2-HW-RTS103C1R2M6L201-A | RTS103C1R2M6L201 | 527-RTS103C1R2M6L201 | $2.2700 | $4.54 | manual |
| 2 |  | HW-C2-HW-S3N-A | S3N | 512-S3N | $0.6700 | $1.34 | manual |
| 2 |  | HW-C2-HW-SSW-103-01-L-D-A | SSW-103-01-L-D | 200-SSW10301LD | $1.3400 | $2.68 | manual |
| 1 |  | HW-C2-HW-SSW-104-01-L-D-A | SSW-104-01-L-D | 200-SSW10401LD | $1.6900 | $1.69 | manual |
| 2 |  | HW-C2-HW-SSW-108-01-L-D-A | SSW-108-01-L-D | 200-SSW10801LD | $2.3500 | $4.70 | manual |
| 1 |  | HW-C2-HW-SSW-110-01-F-D-A | SSW-110-01-F-D |  | N/A | N/A | manual |
| 1 |  | HW-C2-HW-STS41A-AWLB-R3-A | STS41A-AWLB-R3 | 403-STS41A-AWLB-R3 | $1.1300 | $1.13 | manual |
| 6 |  | HW-C2-HW-STTH112A-A | STTH112A | 511-STTH112A | $0.5900 | $3.54 | manual |
| 6 |  | HW-C2-HW-SXH-001T-P0-6-A | SXH-001T-P0.6 | 306-SXH-001T-P0.6 | $0.1000 | $0.60 | manual |
| 4 |  | HW-C2-HW-SZMMSZ4678T1G-A | SZMMSZ4678T1G | 863-SZMMSZ4678T1G | $0.4300 | $1.72 | manual |
| 21 |  | HW-C2-HW-TESTPOINT-TH-RED-A | Testpoint TH, RED | 534-5000 | $0.2930 | $6.15 | manual |
| 1 |  | HW-C2-HW-TPS389006ADJRTER-A | TPS389006ADJRTER | 595-TPS389006ADJRTER | $5.1000 | $5.10 | manual |
| 2 |  | HW-C2-HW-TS40-66-50-R-260-SMT-TR-A | TS40-66-50-R-260-SMT-TR | 179-TS406650R260S | $0.4800 | $0.96 | manual |
| 2 |  | HW-C2-HW-TSW-103-18-G-D-A | TSW-103-18-G-D | 200-TSW10318GD | $1.0100 | $2.02 | manual |
| 2 |  | HW-C2-HW-TSW-108-18-F-D-A | TSW-108-18-F-D | 200-TSW10818FD | $1.4500 | $2.90 | manual |
| 1 |  | HW-C2-HW-TSW-110-18-T-D-A | TSW-110-18-T-D | 200-TSW11018TD | $1.5800 | $1.58 | manual |
| 13 |  | HW-C2-HW-UCM1H101MCL1GS-A | UCM1H101MCL1GS | 647-UCM1H101MCL1GS | $0.3250 | $4.23 | manual |
| 60 |  | HW-C2-HW-UCS2D331MHD-A | UCS2D331MHD | 647-UCS2D331MHD | $2.1600 | $129.60 | manual |
| 1 |  | HW-C2-HW-UJ2-B-HR-G-V-A | UJ2-B-HR-G-V | 179-UJ2-B-HR-G-V | $1.7000 | $1.70 | manual |
| 18 |  | HW-C2-HW-VY1222M47Y5UQ6TV0-A | VY1222M47Y5UQ6TV0 | 72-VY1222M47Y5UQ6TV0 | $0.2710 | $4.88 | manual |
| 27 |  | HW-C2-RES-10K-A | 10k 1210 | 603-AC1210JR-0710KL | $0.0500 | $1.35 | manual |
| 4 |  | HW-C2-RES-120-A | 120 1210 | 603-AC1210FR-07120RL | $0.1000 | $0.40 | manual |
| 17 |  | HW-C2-RES-1K-A | 1k 1210 | 603-RC1210FR-071KL | $0.0490 | $0.83 | manual |
| 12 |  | HW-C2-RES-2R7-A | 2.7 ohm 1210 | 667-ERJ-14BQF2R7U | $0.2340 | $2.81 | manual |
| 16 |  | HW-C2-RES-20K-A | 20k 1210 resistor | 667-ERJ-P14F2002U | $0.2450 | $3.92 | manual |
| 1 |  | HW-C2-RES-220-A | 220 1210 | 603-RC1210FR-07220RL | $0.1000 | $0.10 | manual |
| 3 |  | HW-C2-RES-3K-A | 3k 1210 1% | 603-RC1210FR-073KL | $0.1000 | $0.30 | manual |
| 3 |  | HW-C2-RES-4K7-A | 4.7k 1210 | 71-CRCW12104K70FKEAH | $0.5900 | $1.77 | manual |
| 1 |  | HW-C2-RES-499K-A | 499kohm 1210 resistor | 667-ERJ-P14F4993U | $0.4400 | $0.44 | manual |
| 2 |  | HW-C2-RES-560-A | 560ohm 1210 resistor | 667-ERJ-P14F5600U | $0.4400 | $0.88 | manual |
| 16 |  | HW-C2-RES-250K-A | Thick Film Resistors - SMD 1/2watt 249Kohms 1% | 71-CRCW1210-249K-E3 | $0.0700 | $1.12 | manual |

**Mouser subtotal:** $1733.29

## PCB Fabrication

| Qty | Order | Internal P/N | Description | Part Number | Unit Price | Line Total | Source |
|-----|---|---|---|---|---|---|---|
| 1 |  | HW-C2-PCB-CTRL-A | ControlBoard | ControlBoard | N/A | N/A | unknown |
| 1 |  | HW-C2-PCB-DCBUSCAP-A | DCBusCapacitorBoard | DCBusCapacitorBoard | N/A | N/A | unknown |
| 1 |  | HW-C2-PCB-DCFLT-A | DCBusFilter | DCBusFilter | N/A | N/A | unknown |
| 1 |  | HW-C2-PCB-GD-A | GateDriver | GateDriver | N/A | N/A | unknown |
| 1 |  | HW-C2-PCB-IO-A | IOBoard | IOBoard | N/A | N/A | unknown |

**PCB Fabrication subtotal:** $0.00

## SendCutSend

| Qty | Order | Internal P/N | Description | Part Number | Unit Price | Line Total | Source |
|-----|---|---|---|---|---|---|---|
| 6 |  | HW-C2-3DP-DC-LINK-MODULE-HOLDER-SP-A | DC Link Module Holder Spacer - Printed | DC Link Module Holder Spacer - Printed | N/A | N/A | sendcutsend_folder |
| 3 |  | HW-C2-3DP-DCLSPCR-PRINTED-A | HW-C2-DCLSPCR-PRINTED-B | HW-C2-DCLSPCR-PRINTED-B | N/A | N/A | sendcutsend_folder |
| 1 |  | HW-C2-3DP-SHELL-PRINTED-A | HW-C2-SHELL-PRINTED-A | HW-C2-SHELL-PRINTED-A | N/A | N/A | sendcutsend_folder |
| 2 |  | HW-C2-BB-DCLBB-A | HW-C2-DCLBB-A | HW-C2-DCLBB-A | $52.6400 | $105.28 | sendcutsend_folder |
| 3 |  | HW-C2-BB-PBB-A | HW-C2-PBB-A | HW-C2-PBB-A | $20.3200 | $60.96 | sendcutsend_folder |
| 1 |  | HW-C2-HW-DC-LINK-MODULE-HOLDER-A | DC Link Module Holder - 200V Class | DC Link Module Holder - 200V Class | N/A | N/A | sendcutsend_folder |
| 1 |  | HW-C2-HW-THERMAL-PAD-CUTTING-STEN-A | Thermal Pad Cutting Stencil | Thermal Pad Cutting Stencil | N/A | N/A | sendcutsend_folder |
| 1 |  | HW-C2-PLT-BSP-A | HW-C2-BSP-A | HW-C2-BSP-A | $207.5400 | $207.54 | sendcutsend_folder |
| 1 |  | HW-C2-PLT-CHSP-A | HW-C2-CHSP-B | HW-C2-CHSP-B | $42.6400 | $42.64 | sendcutsend_folder |

**SendCutSend subtotal:** $416.42

---

## Grand Total (1 unit): **$2149.71**

## Quantity Scaling

| Quantity | Estimated Total |
|---|---|
| 1 | $2149.71 |
| 2 | $4299.42 |
| 3 | $6449.13 |
| 5 | $10748.56 |
| 10 | $21497.11 |

## Pack Rounding & Stock

| Part | Need | On Hand | Order | Leftover |
|---|---|---|---|---|
| 90128A232 | 8 | - | 1 pack x 100 | 92 |
| 90225A102 | 5 | - | 1 pack x 50 | 45 |
| 91292A134 | 18 | - | 1 pack x 50 | 32 |
| 91502A180 | 6 | - | 1 pack x 25 | 19 |
| 91502A183 | 6 | - | 1 pack x 10 | 4 |
| 98044A224 | 25 | - | 1 pack x 25 | 0 |

## Unknown / Missing Prices

- CapacitorTempSenseHarness (assembly)
- CurrentSenseHarness (assembly)
- GDVSHarness (assembly)
- TempSenseHarness (assembly)
- 1821A55 (mcmaster)
- 6926K352 (mcmaster)
- 6926K56 (mcmaster)
- 7381K23 (mcmaster)
- 90128A232 (mcmaster)
- 90225A102 (mcmaster)
- 91292A108 (mcmaster)
- 91292A134 (mcmaster)
- 91458A112 (mcmaster)
- 91502A180 (mcmaster)
- 91502A183 (mcmaster)
- 92125A228 (mcmaster)
- 94180A351 (mcmaster)
- 94669A190 (mcmaster)
- 94669A196 (mcmaster)
- 94669A199 (mcmaster)
- 96738A257 (mcmaster)
- 98044A224 (mcmaster)
- 0022011042 (mouser)
- 08-50-0113 (mouser)
- 544959-E (mouser)
- 951-GP1500-080-02 (mouser)
- SSW-110-01-F-D (mouser)
- ControlBoard (pcb)
- DCBusCapacitorBoard (pcb)
- DCBusFilter (pcb)
- GateDriver (pcb)
- IOBoard (pcb)
- DC Link Module Holder Spacer - Printed (sendcutsend)
- HW-C2-DCLSPCR-PRINTED-B (sendcutsend)
- HW-C2-SHELL-PRINTED-A (sendcutsend)
- DC Link Module Holder - 200V Class (sendcutsend)
- Thermal Pad Cutting Stencil (sendcutsend)

## SendCutSend Part Details

### DC Link Module Holder Spacer - Printed

- **Qty (per unit):** 6
- **Material:** Nylon (PA12 or PA6/66)
- **Thickness:** N/A mm
- **Finish:** as printed
- **Unit Price:** N/A
- **STEP:** `../Mechanical/Fab/HW-C2-DCLMH-200-SPCR-PRINTED-A/HW-C2-DCLMH-200-SPCR-PRINTED-A.step`

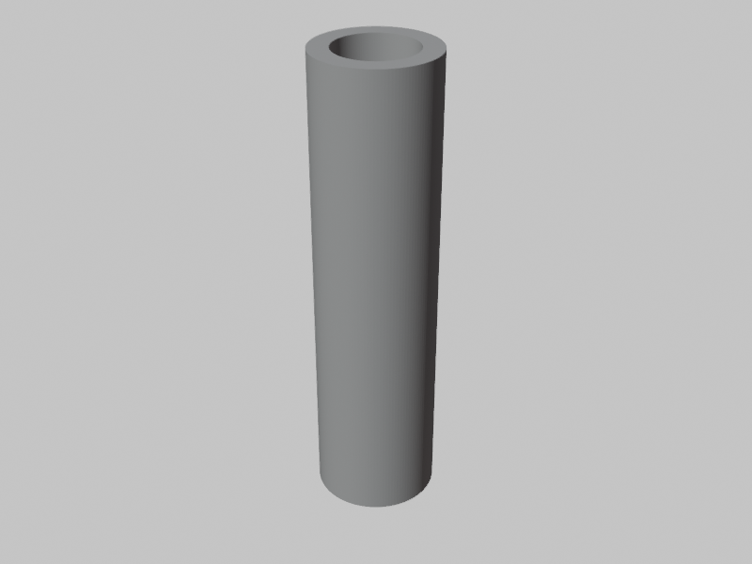
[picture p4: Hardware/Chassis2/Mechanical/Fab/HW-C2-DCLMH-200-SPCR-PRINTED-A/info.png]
DC Link Module Holder Spacer - Printed


### HW-C2-DCLSPCR-PRINTED-B

- **Qty (per unit):** 3
- **Material:** Nylon (PA12 or PA6/66, solid)
- **Thickness:**  mm
- **Finish:** as printed
- **Unit Price:** N/A
- **STEP:** `../Mechanical/Fab/HW-C2-DCLSPCR-PRINTED-B/HW-C2-DCLSPCR-PRINTED-B.step`

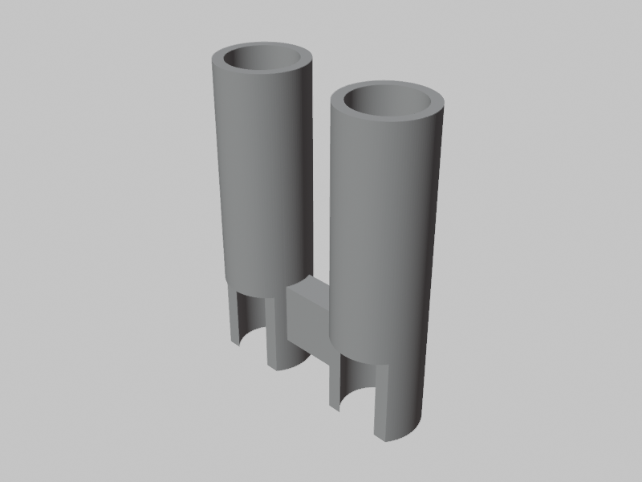
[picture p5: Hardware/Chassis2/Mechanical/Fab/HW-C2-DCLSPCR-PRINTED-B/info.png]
HW-C2-DCLSPCR-PRINTED-B


### HW-C2-SHELL-PRINTED-A

- **Qty (per unit):** 1
- **Material:** Nylon (PA12 or PA6/66, solid)
- **Thickness:**  mm
- **Finish:** as printed
- **Unit Price:** N/A
- **STEP:** `../Mechanical/Fab/HW-C2-SHELL-PRINTED-A/HW-C2-SHELL-PRINTED-A.step`

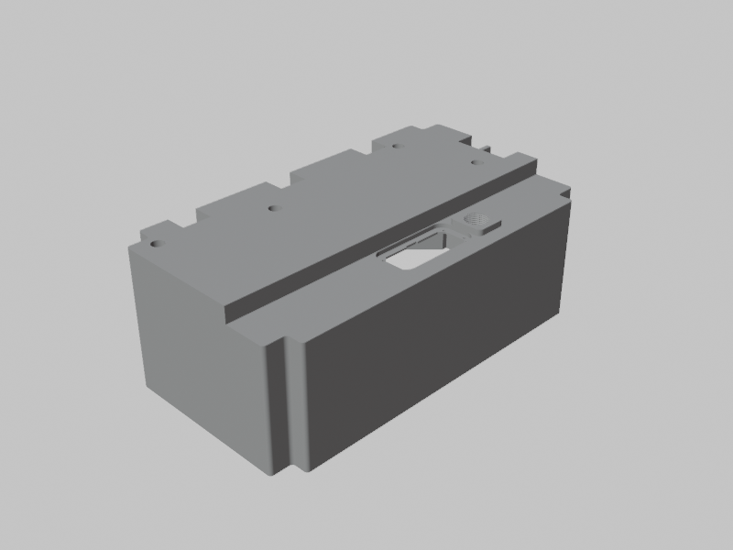
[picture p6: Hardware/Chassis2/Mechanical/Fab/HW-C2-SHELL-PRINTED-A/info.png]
HW-C2-SHELL-PRINTED-A


### HW-C2-DCLBB-A

- **Qty (per unit):** 2
- **Material:** Copper
- **Thickness:** 4.75 mm
- **Finish:** Bending
- **Unit Price:** $52.64
- **STEP:** `../Mechanical/Fab/HW-C2-DCLBB-A/HW-C2-DCLBB-A.step`

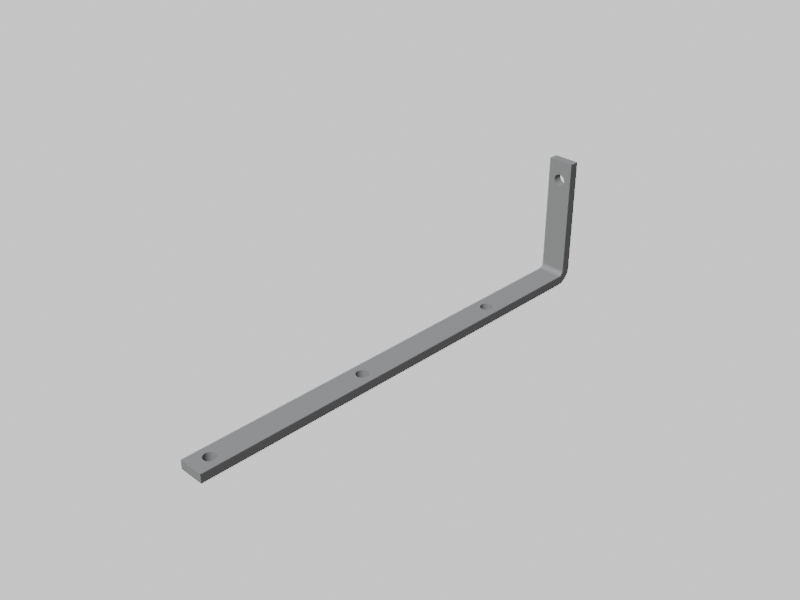
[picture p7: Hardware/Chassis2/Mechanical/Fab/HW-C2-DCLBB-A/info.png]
HW-C2-DCLBB-A


### HW-C2-PBB-A

- **Qty (per unit):** 3
- **Material:** Copper
- **Thickness:** 4.75 mm
- **Finish:** Bending
- **Unit Price:** $20.32
- **STEP:** `../Mechanical/Fab/HW-C2-PBB-A/HW-C2-PBB-A.step`

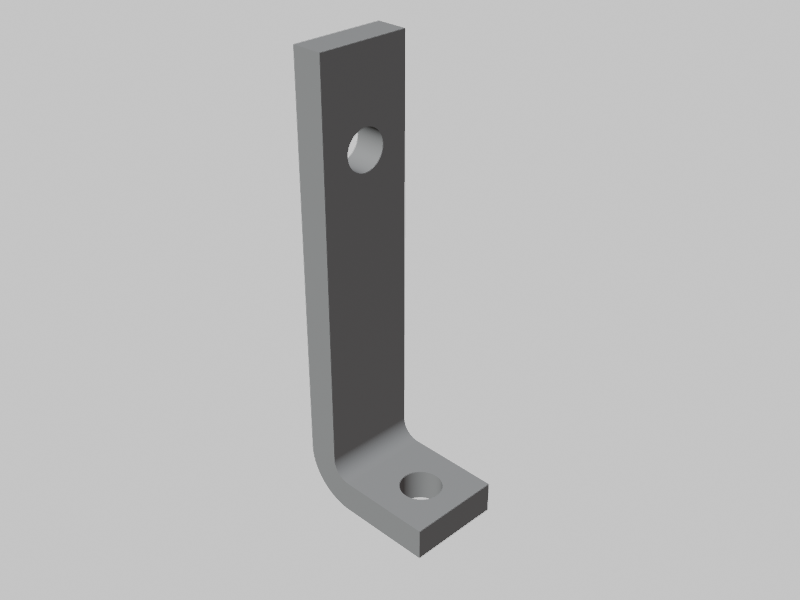
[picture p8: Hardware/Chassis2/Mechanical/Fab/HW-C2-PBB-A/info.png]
HW-C2-PBB-A


### DC Link Module Holder - 200V Class

- **Qty (per unit):** 1
- **Material:** 
- **Thickness:** 35.50 mm
- **Finish:** as printed
- **Unit Price:** N/A
- **STEP:** `../Mechanical/Fab/HW-C2-DCLMH-200-PRINTED-B/HW-C2-DCLMH-200-PRINTED-B.step`

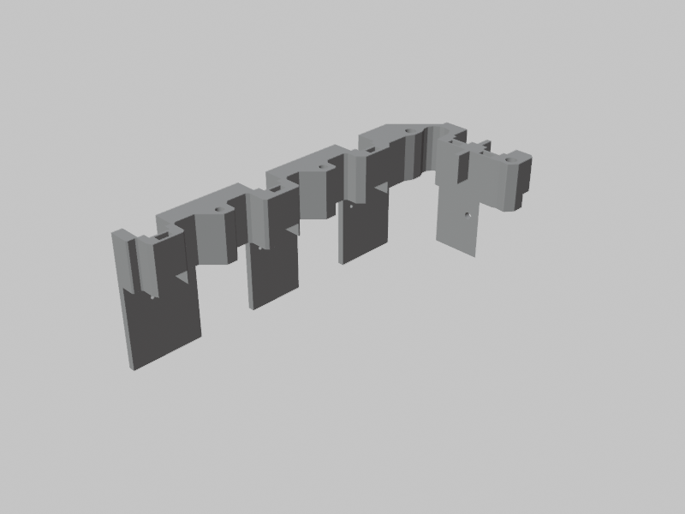
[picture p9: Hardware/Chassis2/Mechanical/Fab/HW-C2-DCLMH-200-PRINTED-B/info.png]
DC Link Module Holder - 200V Class


### Thermal Pad Cutting Stencil

- **Qty (per unit):** 1
- **Material:** PLA
- **Thickness:** N/A mm
- **Finish:** as printed
- **Unit Price:** N/A
- **STEP:** `../Mechanical/Fab/HW-C2-THRMLPD-STNCL-A/HW-C2-THRMLPD-STNCL-A.step`

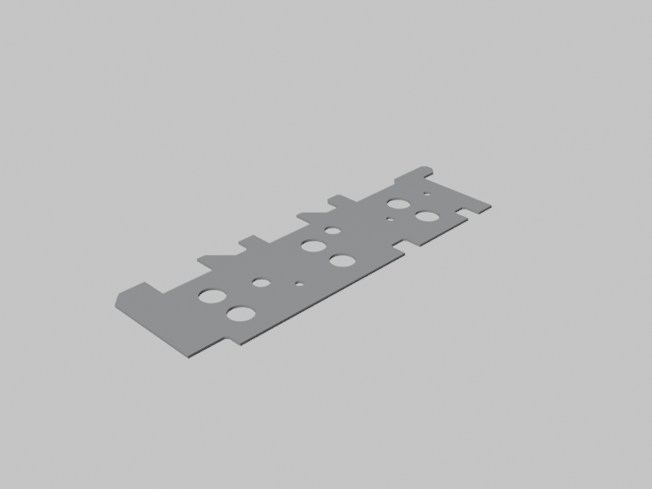
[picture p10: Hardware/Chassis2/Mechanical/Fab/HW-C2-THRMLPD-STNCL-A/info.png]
Thermal Pad Cutting Stencil


### HW-C2-BSP-A

- **Qty (per unit):** 1
- **Material:** 6061 T6 Aluminum
- **Thickness:** 9.52 mm
- **Finish:** Deburring, Tapping
- **Unit Price:** $207.54
- **STEP:** `../Mechanical/Fab/HW-C2-BSP-A/HW-C2-BSP-A.step`

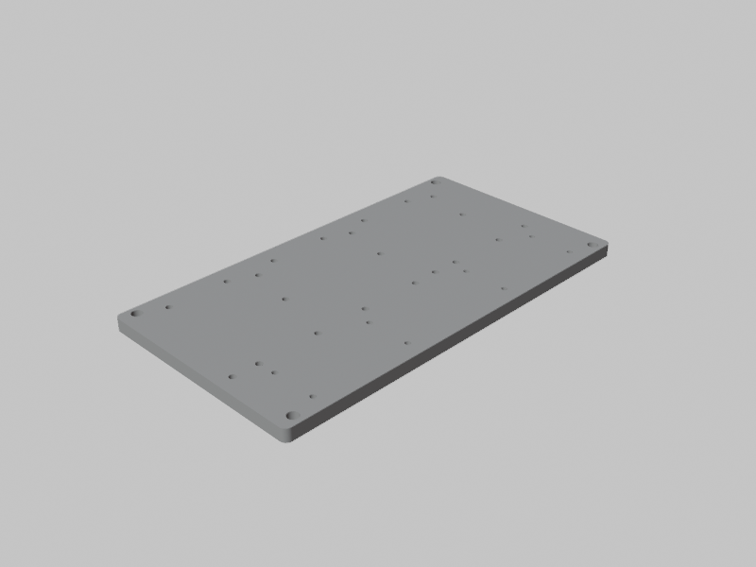
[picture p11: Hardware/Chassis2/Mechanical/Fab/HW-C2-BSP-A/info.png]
HW-C2-BSP-A


### HW-C2-CHSP-B

- **Qty (per unit):** 1
- **Material:** 6061 T6 Aluminum
- **Thickness:** 6.35 mm
- **Finish:** Deburring
- **Unit Price:** $42.64
- **STEP:** `../Mechanical/Fab/HW-C2-CHSP-B/HW-C2-CHSP-B.step`

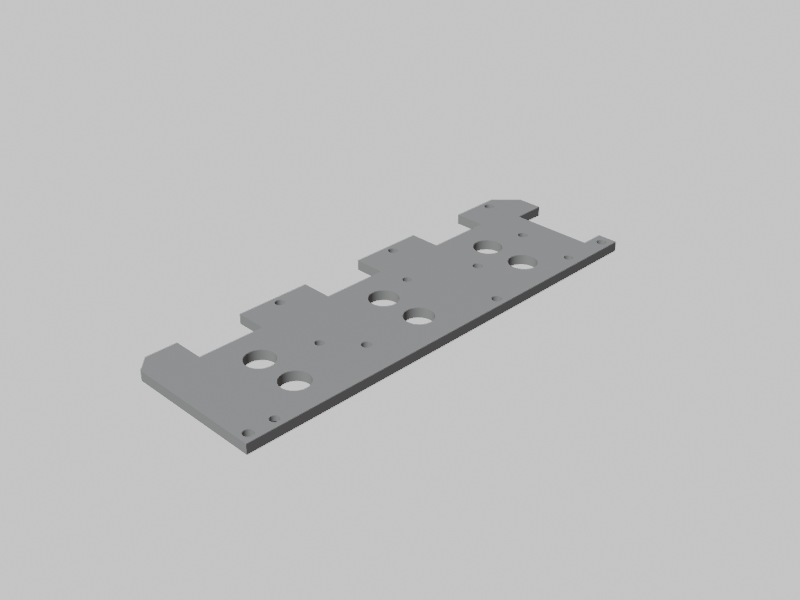
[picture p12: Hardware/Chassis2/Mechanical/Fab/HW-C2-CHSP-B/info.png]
HW-C2-CHSP-B


## Fabrication Package

| PCB Board | Fab Files | Zip | Fab Price |
|---|---|-----|---|
| ControlBoard | 32 | built | **missing** |
| DCBusCapacitorBoard | 26 | built | **missing** |
| DCBusFilter | 28 | built | **missing** |
| GateDriver | 30 | built | **missing** |
| IOBoard | 30 | built | **missing** |

| Fab Part | Rev | Qty | STEP | info.txt | Price | Spec |
|---|-----|-----|---|---|---|---|
| HW-C2-BSP-A | A | 1 | yes | yes | $207.54 | 6061 T6 Aluminum / 9.52 mm / Sheet Cutting / Deburring, Tapping |
| HW-C2-CHSP-B | A | 1 | yes | yes | $42.64 | 6061 T6 Aluminum / 6.35 mm / Sheet Cutting / Deburring |
| HW-C2-DCLBB-A | A | 2 | yes | yes | $52.64 | Copper / 4.75 mm / Sheet Cutting / Bending |
| HW-C2-DCLMH-200-PRINTED-B | A | 1 | yes | yes | **missing** | 35.50 mm / 3D Printing / as printed |
| HW-C2-DCLMH-200-SPCR-PRINTED-A | A | 6 | yes | yes | **missing** | Nylon (PA12 or PA6/66) / 3D Printing / as printed |
| HW-C2-DCLMH-450-PRINTED-A | A | 1 | yes | yes | **missing** | Nylon (PA12 or PA6/66) / 31.50 mm / 3D Printing / as printed |
| HW-C2-DCLMH-450-SPCR-PRINTED-A | A | 6 | yes | yes | **missing** | Nylon (PA12 or PA6/66) / 3D Printing / as printed |
| HW-C2-DCLSPCR-PRINTED-B | A | 3 | yes | yes | **missing** | Nylon (PA12 or PA6/66, solid) / 3D Printing / as printed |
| HW-C2-FR-BSP-A | A | 2 | yes | yes | **missing** | 5052 H32 Aluminum / 3.0 mm / Sheet Cutting / Deburring, Bending |
| HW-C2-FR-CLPHLD-A | A | 1 | yes | yes | **missing** | 5052 H32 Aluminum / 3.0 mm / Sheet Cutting / Deburring, Bending |
| HW-C2-PBB-A | A | 3 | yes | yes | $20.32 | Copper / 4.75 mm / Sheet Cutting / Bending |
| HW-C2-SHELL-PRINTED-A | A | 1 | yes | yes | **missing** | Nylon (PA12 or PA6/66, solid) / 3D Printing / as printed |
| HW-C2-THRMLPD-STNCL-A | A | 1 | yes | yes | **missing** | PLA / 3D Printing / as printed |
| HW-C3-FR-CSP-A | A | 4 | yes | yes | **missing** | 5052 H32 Aluminum / 3.0 mm / Sheet Cutting / Deburring, Bending |
| HW-C3-FR-FRNLID-A | A | 2 | yes | yes | **missing** | 5052 H32 Aluminum / 3.0 mm / Sheet Cutting / Deburring, Bending |

| Harness | Qty/Chassis | Rev | BOM CSV |
|---|---|-----|---|
| CapacitorTempSenseHarness | 1 | A | yes |
| CurrentSenseHarness | 4 | A | yes |
| GDVSHarness | 1 | A | yes |
| TempSenseHarness | 2 | A | yes |

**Not ready:**
- board ControlBoard: no fab price (fab pcb-price ControlBoard <usd>)
- board DCBusCapacitorBoard: no fab price (fab pcb-price DCBusCapacitorBoard <usd>)
- board DCBusFilter: no fab price (fab pcb-price DCBusFilter <usd>)
- board GateDriver: no fab price (fab pcb-price GateDriver <usd>)
- board IOBoard: no fab price (fab pcb-price IOBoard <usd>)
- fab part HW-C2-DCLMH-200-PRINTED-B: no price
- fab part HW-C2-DCLMH-200-SPCR-PRINTED-A: no price
- fab part HW-C2-DCLMH-450-PRINTED-A: no price
- fab part HW-C2-DCLMH-450-SPCR-PRINTED-A: no price
- fab part HW-C2-DCLSPCR-PRINTED-B: no price
- fab part HW-C2-FR-BSP-A: no price
- fab part HW-C2-FR-CLPHLD-A: no price
- fab part HW-C2-SHELL-PRINTED-A: no price
- fab part HW-C2-THRMLPD-STNCL-A: no price
- fab part HW-C3-FR-CSP-A: no price
- fab part HW-C3-FR-FRNLID-A: no price

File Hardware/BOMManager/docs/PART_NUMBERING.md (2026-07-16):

# Internal Part Numbering Conventions

Every BOM line gets an internal part number (IPN) in the format:

```text
HW-<CHASSIS>-<CATEGORY>-<DESCRIPTOR>-<REV>
```

Examples:

- `HW-C2-PCB-CTRL-A` — Chassis2 control board PCB, revision A
- `HW-C2-PCB-GD-A` — Chassis2 gate driver PCB, revision A
- `HW-C2-WH-GDVS-A` — Chassis2 gate-driver-to-??? wiring harness, revision A
- `HW-C2-BB-DCLBB-A` — Chassis2 DC link bus bar, revision A
- `HW-C2-PLT-CHSP-A` — Chassis2 capacitor heat spreader plate, revision A
- `HW-C2-RES-10K1210-A` — Chassis2 10k 1210 resistor
- `HW-C2-IC-STM32H723ZGTX-A` — Chassis2 STM32 microcontroller

The registry lives in `bom_manager/data/part_numbers.json` and is generated automatically. Registry keys are **identity-based** (`chassis|category|footprint|designation`, or `chassis|category|fab:<folder>` for fabricated parts), so editing a description or a friendly `PartName` never renumbers a part. (Registries written by older versions used description-based keys; entries are migrated automatically on first contact, keeping their part numbers.) The tool also keeps a descriptor registry at `bom_manager/data/part_descriptors.json` so you only have to name a part once.

## Category reference

Use these categories when prompted, or let the tool auto-detect them.

| Category | Prefix | Use for |
|---|---|---|
| `pcb` | `HW-PCB` | Printed circuit boards fabricated by a PCB house |
| `busbar` | `HW-BB` | Bus bars, current-carrying bars, tie bars |
| `plate` | `HW-PLT` | Heat spreaders, mounting plates, cover plates, shields |
| `bracket` | `HW-BRK` | Mounting brackets, standoffs, supports |
| `wiring` | `HW-WH` | Wiring harnesses, wire assemblies, leads |
| `cable` | `HW-CBL` | Discrete cables, pre-made cable assemblies |
| `3dprint` | `HW-3DP` | 3D printed parts |
| `connector` | `HW-CONN` | Connectors, headers, sockets, terminals |
| `fastener` | `HW-FST` | Screws, bolts, nuts, washers, standoffs |
| `mechanical` | `HW-MECH` | Other McMaster / mechanical hardware |
| `electrical` | `HW-ELEC` | Misc electrical parts not covered above |
| `resistor` | `HW-RES` | SMD / through-hole resistors |
| `capacitor` | `HW-CAP` | SMD / through-hole capacitors |
| `ic` | `HW-IC` | ICs, crystals, microcontrollers, isolators |
| `assembly` | `HW-ASSY` | Sub-assemblies made of multiple parts |
| `other` | `HW-HW` | Anything that does not fit above |

## How descriptors are chosen

The tool tries to pick a good descriptor automatically and only asks you when it needs a human decision.

| Part class | How descriptor is chosen |
|---|---|
| **PCB fab** | Pre-registered by `new board` (or prompted on first run). Default is an abbreviation of the board folder name (`ControlBoard` → `CTRL`). |
| **Wiring harness** | Pre-registered by `new harness`. Default is the harness folder/document name. |
| **Wire / cable in a harness** | Auto from the value (e.g. `WIRE 10AWG RED` → `WIRE-10AWG-RED`), no prompt. |
| **Bus bars / plates / brackets / 3D prints** | Auto from the fabricated-part folder name (`DCLBB`, `CHSP`, `BSP`). |
| **Mechanical / fasteners** | Auto from the McMaster part number or slugified description. |
| **Resistors / capacitors / ICs / connectors** | Auto from value, footprint, or manufacturer part number. |

You can edit `bom_manager/data/part_descriptors.json` directly at any time to rename descriptors. After editing, rerun `python3 bom.py generate`.

### Example descriptor registry

```json
{
  "Chassis2|pcb|controlboard": "CTRL",
  "Chassis2|pcb|gatedriver": "GD",
  "Chassis2|pcb|dcbuscapacitorboard": "DCBUSCAP",
  "Chassis2|pcb|dcbusfilter": "DCFLT",
  "Chassis2|pcb|ioboard": "IO"
}
```

## Concrete examples

| Real-world part | Category | Descriptor | Resulting IPN |
|---|---|---|---|
| Control board PCB | `pcb` | `CTRL` | `HW-C2-PCB-CTRL-A` |
| Gate driver PCB | `pcb` | `GD` | `HW-C2-PCB-GD-A` |
| DC bus capacitor bulk board PCB | `pcb` | `DCBUSCAP` | `HW-C2-PCB-DCBUSCAP-A` |
| DC bus filter PCB | `pcb` | `DCFLT` | `HW-C2-PCB-DCFLT-A` |
| IO board PCB | `pcb` | `IO` | `HW-C2-PCB-IO-A` |
| DC link positive bus bar | `busbar` | `DCLBB` | `HW-C2-BB-DCLBB-A` |
| Phase bus bar | `busbar` | `PBB` | `HW-C2-BB-PBB-A` |
| Capacitor heat spreader plate | `plate` | `CHSP` | `HW-C2-PLT-CHSP-A` |
| Base / structural plate | `plate` | `BSP` | `HW-C2-PLT-BSP-A` |
| IGBT module mounting bracket | `bracket` | `IGBTBRK` | `HW-C2-BRK-IGBTBRK-A` |
| Gate driver to control board wiring harness | `wiring` | `GDCTRL` | `HW-C2-WH-GDCTRL-A` |
| Current sensor cable | `cable` | `CURSENS` | `HW-C2-CBL-CURSENS-A` |
| 3D printed connector cover | `3dprint` | `CONCOV` | `HW-C2-3DP-CONCOV-A` |
| M3x10 socket head screw | `fastener` | `M3X10SHS` | `HW-C2-FST-M3X10SHS-A` |
| 1210 10k resistor | `resistor` | `10K1210` | `HW-C2-RES-10K1210-A` |
| 1210 100nF capacitor | `capacitor` | `100NF100V1210` | `HW-C2-CAP-100NF100V1210-A` |
| STM32 microcontroller | `ic` | `STM32H723ZGTX` | `HW-C2-IC-STM32H723ZGTX-A` |

## Naming fabricated mechanical parts

For SendCutSend / fabricated parts, use the folder name as the part name. The recommended convention is:

```text
HW-<CHASSIS>-<FUNCTION>-<REV>
```

Examples:

| Folder name | Part meaning | Category | IPN |
|---|---|---|-----|
| `HW-C2-DCLBB-A` | Chassis2 DC Link Bus Bar | `busbar` | `HW-C2-BB-DCLBB-A` |
| `HW-C2-PBB-A` | Chassis2 Phase Bus Bar | `busbar` | `HW-C2-BB-PBB-A` |
| `HW-C2-CHSP-A` | Chassis2 Capacitor Heat Spreader Plate | `plate` | `HW-C2-PLT-CHSP-A` |
| `HW-C2-BSP-A` | Chassis2 Base / Back Structural Plate | `plate` | `HW-C2-PLT-BSP-A` |

Abbreviations the tool auto-detects for category:

- `DCLBB`, `DCLB`, `PBB`, `BB` → `busbar`
- `CHSP`, `HSP`, `HS`, `BSP` → `plate`
- `BRK`, `BRACKET` → `bracket`

## Multiple chassis / sizes

Part numbers are chassis-specific by default. A physically different part in another chassis gets a different chassis prefix, even if the descriptor is the same.

```text
Chassis2 DC link bus bar    → HW-C2-BB-DCLBB-A
Chassis3 DC link bus bar    → HW-C3-BB-DCLBB-A  (different size = different PN)
```

Use the descriptor to identify the function and the chassis prefix to identify the size/revision of the overall chassis.

## Revisions

Bump a revision when the part changes enough that you need to distinguish old stock from new stock:

- `A` — first revision
- `B` — changed hole pattern, material, thickness, connector pinout, etc.
- `C`, `D`, ... — subsequent changes
- The tool starts at `A` automatically.

For off-the-shelf commodity parts (resistors, capacitors, ICs), the revision letter is kept for format consistency but is usually left at `A` because you are not revising the part itself.

To bump a revision:

```text
bom> rev list
bom> rev bump DCLBB --note "widen mounting holes"
```

The query is fuzzy — a full IPN, a descriptor, or description text. The bump is
recorded in the entry's `history` (rev, date, note) inside `part_numbers.json`.

Revisions are **decoupled from file and folder names**: bumping writes `Rev=`
into a fabricated part's `info.txt` and never renames its folder or STEP file,
so CAD documents and vendor uploads keep pointing at the same place.

## Wiring harnesses

A harness documented as a KiCad schematic gets an assembly line
like `HW-C2-WH-GD-A` once you drop the schematic's BOM CSV export into
`Hardware/<Chassis>/Wiring/<Name>/` (or its `Fab/` subfolder, same layout as
boards). Create the folder with `new harness` —
it pre-registers the descriptor and its README has the exact Eeschema export
settings. Naming the folder with the full part number (`HW-C2-WH-GD-A`) makes
`generate` adopt that number with no prompt at all. The harness's connectors,
crimps, and wire appear as normal BOM lines with their own IPNs.

## Auto-detection

The tool guesses the category from the footprint, description, and source/folder name:

- `R_1210...` footprints → `resistor`
- `C_1210...` footprints → `capacitor`
- Footprints containing `IC`, `SOIC`, `QFP`, etc. → `ic`
- Description containing "bus bar" or folder name containing `DCLBB`/`PBB` → `busbar`
- Description containing "plate" or folder name containing `CHSP`/`HSP`/`BSP` → `plate`
- Description containing "bracket" or folder name containing `BRK` → `bracket`
- KiCad board source → `pcb`
- McMaster mechanical parts → `mechanical`

If it guesses wrong, you can override the category with `add` (the wizard's Type prompt) in the shell.

## Non-interactive / CI usage

If you run the tool in a script and it encounters a part that needs a descriptor, it will prompt by default. Use `--no-prompt` to make it fail with a clear error instead:

```bash
python3 bom.py generate --no-prompt
```

Add the missing descriptors to `bom_manager/data/part_descriptors.json` and rerun.

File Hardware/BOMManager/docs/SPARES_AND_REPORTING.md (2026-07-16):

# Spares Policies and Price Reporting

## Spares Policies

Controlled by `--spares`:

| Policy | Behavior |
|---|---|
| `none` | Exact BOM quantity. |
| `cheap` | Round resistors, capacitors, and mechanical fasteners to standard pack sizes (10, 25, 50, 100, 200, 500, 1000). |
| `all` | Add `--spares-pct` percent to every line (default 10%). |

Examples:

```bash
python3 bom.py generate --spares cheap
python3 bom.py generate --spares all --spares-pct 20
```

Spares are applied to the *needed* quantity before pack-size rounding, so a
line needing 8 screws at pack size 25 with `--spares cheap` orders 1 pack
(need rounds to 10, then to 1 box of 25).

## Price Report

`Hardware/Chassis2/FabricationData/Pricing_Report.md` is regenerated on every run and contains:

- One section per vendor with line items, order info, unit price, line total, and price source.
- Vendor subtotals.
- Grand total for the requested quantity.
- A quantity-scaling table (default 3, 5, 10, 25 units).
- A **Pack Rounding & Stock** section: need vs. on-hand vs. packs ordered vs. leftover.
- A **Fabrication Package** checklist: per-board fab files/zip/price, per-part STEP/info/price/rev, harness CSVs, and anything not ready.
- A list of parts with unknown/missing prices.
- A SendCutSend details section with material, thickness, finish, STEP path, and embedded `info.png` images.

The report is Markdown so it renders nicely in GitHub/GitLab and can be committed to track project cost over time. Each chassis gets its own report under `Hardware/<Chassis>/FabricationData/`.

## Quantity Scaling

Use `--qty N` to scale the whole BOM:

```bash
python3 bom.py generate --qty 5
```

The consolidated CSV quantities are multiplied by N (order quantities are
computed from the scaled need), and the report grand total reflects N units.
You can change the scaling table with `--extra-qtys`:

```bash
python3 bom.py generate --qty 1 --extra-qtys 2,5,10,25,50
```

## Price Sources

Each line shows where the price came from:

- `mouser_api`, `digikey_api`, `octopart_api` — live lookup (needs API keys).
- `mouser_cart_import`, `mcmaster_order_import`, `jlcpcb_order_import` — pasted cart/order imports.
- `sendcutsend_folder` — the part's `info.txt`.
- `manual` — set by hand in the shell (`price`, `pack`, `fab pcb-price`).
- `cache` — from `price_cache.json`.
- `unknown` — no price found; listed in the report for follow-up.

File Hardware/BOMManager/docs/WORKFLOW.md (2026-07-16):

# BOM Manager Workflow

The whole flow runs inside the interactive shell:

```bash
cd Hardware/BOMManager
python3 bom.py
```

(Everything below also works one-shot, e.g. `python3 bom.py generate --qty 5`.)

## 1. Feed the tool your design data

**PCB BOMs** — for each board, in KiCad: **File → Fabrication Outputs → BOM CSV**,
saved as `Hardware/<Chassis>/Boards/<Board>/Fab/<Board>.csv`. The same folder is
zipped for the fab house, so put gerbers/drill files there too.

**New parts** — scaffold instead of hand-creating folders:

```text
bom> new fab Phase Bus Bar        # Mechanical/Fab/HW-C2-PBB-A/ + info.txt + README
bom> new board PowerBoard         # Boards/PowerBoard/Fab/ + README, descriptor registered
bom> new harness GateDriverHarness # Wiring/GateDriverHarness/Fab/ + README
```

**Wiring harnesses** — document as a KiCad *schematic only* (no layout). Place
symbols for connectors/crimps/wire (wire values start with `WIRE`), then export
the BOM CSV from Eeschema (**Tools → Generate BOM**) into the harness folder.
The scaffolded README spells out the exact export settings. Components land in
the BOM like any other part; the harness itself appears as a `HW-C2-WH-...`
assembly line.

**Purchased hardware** — the tool owns `MechanicalBOM.txt`; do not hand-edit:

```text
bom> mech add McMaster 94669A199 12 M3x10 socket head screw
bom> mech set 94669A199 20
bom> mech rm 94669A199
```

## 2. Price things

```text
bom> status           # what still needs attention
bom> add              # wizard: walks BOM lines missing vendor PNs/prices
bom> price 94669A199 3.10
bom> pack 94669A199 25 24.40     # box of 25 at $24.40/box
bom> fab pcb-price ControlBoard 25.24
```

Prices attach to the committed part database. `pack` means: order N packs of
25, not N pieces.

## 3. Generate and order

```text
bom> generate
```

Outputs land in `Hardware/<Chassis>/FabricationData/` (see README). Ordering:

- **Mouser / DigiKey**: upload the respective `*_bom.csv` to the vendor BOM tool.
- **McMaster**: paste `McMaster_Order_Paste.txt` into the cart's
  "Paste part numbers and quantities" box. Quantities are already in packs, and
  parts covered by your shelf stock are left out.
- **SendCutSend**: specs are in the report's fab section; upload the STEP files
  from `Mechanical/Fab/<Part>/`.
- **PCBs**: upload `PCB_Fab_Zips/<Board>.zip` to your fab.

## 4. Import real prices after ordering

Paste the cart/order confirmation (then Ctrl+D):

```text
bom> import mouser
bom> import mcmaster
bom> import sendcutsend       # fills/updates info.txt in Fab folders
bom> import jlcpcb            # per-board PCB fab prices
```

Imported prices go to the local cache **and** persist into the committed part
database, so cost history survives a fresh clone.

## 5. Receive parts, record leftovers

```text
bom> stock 94669A199 19       # 19 screws left over
```

Stock lives in `inventory.json`, which is gitignored — your shelf is not
project data. Future `generate` runs subtract it: covered parts order 0 packs
and show up in the report's **Pack Rounding & Stock** section.

## 6. Revisions

```text
bom> rev list
bom> rev bump DCLBB --note "widen mounting holes"
```

Bumps update the registry (with history) and write `Rev=` into a fabricated
part's `info.txt`. Folders and STEP files are never renamed — CAD and vendor
links keep working, and internal PNs never change when you edit descriptions.

## 7. Track cost over time

Commit `FabricationData/Pricing_Report.md`, `part_database.json`, and
`part_numbers.json`. Rerun `generate` as the design evolves and diff the report.

For scripted/CI runs use `--no-prompt` so the tool errors instead of blocking
when something needs input.

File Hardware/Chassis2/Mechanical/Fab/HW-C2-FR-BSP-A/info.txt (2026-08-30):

PartName=HW-C2-FR-BSP-A
Material=5052 H32 Aluminum
Thickness_mm=3.0
Qty=2
Dimensions_in=16.142x20.197 in
Finish=Deburring, Bending
UnitPrice=
Process=Sheet Cutting
Notes=Front base plate with mounting flanges for the C2 DC/DC converter module chassis frame (left/right pair). Holes: 8x 6.0 mm, 4x 6.6 mm, 32x 11.0 mm.

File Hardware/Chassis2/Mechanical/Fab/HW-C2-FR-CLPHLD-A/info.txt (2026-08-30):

PartName=HW-C2-FR-CLPHLD-A
Material=5052 H32 Aluminum
Thickness_mm=3.0
Qty=1
Dimensions_in=15.906x10.669 in
Finish=Deburring, Bending
UnitPrice=
Process=Sheet Cutting
Notes=Front coldplate holder bracket for the C2 DC/DC converter module; carries the two Boyd 416201U00000G coldplates. Holes: 4x 8.0 mm, 8x 11.0 mm, 6x 25.4 mm.

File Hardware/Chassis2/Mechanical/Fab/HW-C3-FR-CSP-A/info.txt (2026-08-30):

PartName=HW-C3-FR-CSP-A
Material=5052 H32 Aluminum
Thickness_mm=3.0
Qty=4
Dimensions_in=2.559x9.173 in
Finish=Deburring, Bending
UnitPrice=
Process=Sheet Cutting
Notes=Chassis cornerpost (angle profile) for the DC/DC converter module frame; 8x 11.0 mm hex-punched holes take 90720A550 rivet nuts (2 per post). Shared geometry with Chassis 3 front frame.

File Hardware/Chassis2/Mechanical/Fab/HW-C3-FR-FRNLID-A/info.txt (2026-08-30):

PartName=HW-C3-FR-FRNLID-A
Material=5052 H32 Aluminum
Thickness_mm=3.0
Qty=2
Dimensions_in=16.063x11.378 in
Finish=Deburring, Bending
UnitPrice=
Process=Sheet Cutting
Notes=Front cover lid for the DC/DC converter module frame; 6x 9.0 mm lid-retention holes (90166A718 screws). Shared geometry with Chassis 3 cabinet cover.

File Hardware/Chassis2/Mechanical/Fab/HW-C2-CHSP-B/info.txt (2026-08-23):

PartName=HW-C2-CHSP-B
Material=6061 T6 Aluminum
Thickness_mm=6.35
Qty=1
Dimensions_in=11.732x3.78 in
Finish=Deburring
UnitPrice=42.64
Process=Sheet Cutting
Notes=Imported from SendCutSend cart

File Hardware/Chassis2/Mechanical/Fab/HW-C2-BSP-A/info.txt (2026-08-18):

PartName=HW-C2-BSP-A
Material=6061 T6 Aluminum
Thickness_mm=9.52
Qty=1
Dimensions_in=6.693x12.402 in
Finish=Deburring, Tapping
UnitPrice=207.54
Process=Sheet Cutting
Notes=Imported from SendCutSend cart

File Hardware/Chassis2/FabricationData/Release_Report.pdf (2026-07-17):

## HARDWARE RELEASE REPORT

# Traction Inverter

## Chassis: Chassis2 BOM lines: 106 (98 priced) Generated: 2026-07-17

# Cost at quantity

Units | Estimated total
1 | $2,318.90
2 | $4,570.34
3 | $6,816.23
5 | $11,321.50
10 | $22,587.25

### University of California, Santa Cruz — Corzine Lab

Inverter Gen5 — Chassis2 Hardware Release | 2

# Contents

## 1. Order Summary

## 2. Fabrication Package

## 3. Control Board — schematic & PCB layers

## 4. DC Bus Capacitor Board — schematic & PCB layers

## 5. Filter Board — schematic & PCB layers

## 6. Gate Driver Board — schematic & PCB layers

## 7. IO Board — schematic & PCB layers

## 8. Capacitor Temp Sense Wiring Harness — wiring harness

## 9. Current Sensor Wiring Harness — wiring harness

## 10. Gate Drive Wiring Harness — wiring harness

## 11. IGBT Temperature Wiring Harness — wiring harness

## 12. Thermal Analysis — DC Link Module Standoff Heat Path — design document

## 13. Hazard Analysis & Risk Assessment — design document

## 14. User Manual — design document

## 15. Software Architecture Document — design document

## 16. Threat Analysis and Risk Assessment — design document

Inverter Gen5 — Chassis2 Hardware Release | 3

# Order Summary

# Digi-Key

Qty | Internal P/N | Description | Part Number | Unit | Total
1 | HW-C2-HW-3M156058-ND -A | 3M156058-ND | 3M156058-ND | $46.9800 | $46.98
| | | | Subtotal | $46.98

# McMaster-Carr

Qty | Internal P/N | Description | Part Number | Unit | Total
8 (1pk) | HW-C2-MECH-90128A232 -A | 90128A232 | 90128A232 | $10.5500/pk | $10.55
5 (1pk) | HW-C2-MECH-90225A102 -A | 90225A102 | 90225A102 | $12.8000/pk | $12.80
18 (1pk) | HW-C2-MECH-91292A134 -A | 91292A134 | 91292A134 | $11.7200/pk | $11.72
4 (1pk) | HW-C2-MECH-91294A220 -A | 91294A220 | 91294A220 | $12.7400/pk | $12.74
6 (1pk) | HW-C2-MECH-91502A180 -A | 91502A180 | 91502A180 | $19.6500/pk | $19.65
6 (1pk) | HW-C2-MECH-91502A183 -A | 91502A183 | 91502A183 | $17.2700/pk | $17.27
6 | HW-C2-MECH-94669A190 -A | 94669A190 | 94669A190 | $1.3900 | $8.34
6 | HW-C2-MECH-94669A196 -A | 94669A196 | 94669A196 | $2.9600 | $17.76
6 | HW-C2-MECH-94669A199 -A | 94669A199 | 94669A199 | $3.1000 | $18.60
6 | HW-C2-MECH-94669A202 -A | 94669A202 | 94669A202 | $3.2200 | $19.32
25 (1pk) | HW-C2-MECH-98044A224 -A | 98044A224 | 98044A224 | $14.8800/pk | $14.88
| | | | Subtotal | $163.63

# Mouser

Qty | Internal P/N | Description | Part Number | Unit | Total
8 | HW-C2-HW-0022011042-A | 0022011042 | - | N/A | N/A
32 | HW-C2-HW-08-50-0113-A | 08-50-0113 | - | N/A | N/A
70 | HW-C2-CAP-100N-A | 100nF 100V | 80-C1210C104K1RAC | $0.1610 | $11.27
27 | HW-C2-RES-10K-A | 10k 1210 | 603-AC1210JR-0710K L | $0.0500 | $1.35
21 | HW-C2-CAP-10N-A | 10nF 500V | 187-CL32B103KGFNN NE | $0.1430 | $3.00
37 | HW-C2-CAP-10U-A | 10uF 25V | 187-CL32A106KAULN NE | $0.1340 | $4.96

Inverter Gen5 — Chassis2 Hardware Release | 4
Qty | Internal P/N | Description | Part Number | Unit | Total
4 | HW-C2-RES-120-A | 120 1210 | 603-AC1210FR-07120 RL | $0.1000 | $0.40
17 | HW-C2-RES-1K-A | 1k 1210 | 603-RC1210FR-071KL | $0.0490 | $0.83
8 | HW-C2-CAP-1U-A | 1uf 50V | 187-CL32B105KBHNN NE | $0.2400 | $1.92
2 | HW-C2-CAP-2U2-A | 2.2uf 1210 100v | 80-C1210C225J1RAU TO | $0.5200 | $1.04
12 | HW-C2-RES-2R7-A | 2.7 ohm 1210 | 667-ERJ-14BQF2R7U | $0.2340 | $2.81
16 | HW-C2-RES-20K-A | 20k 1210 resistor | 667-ERJ-P14F2002U | $0.2450 | $3.92
4 | HW-C2-HW-22-04-1041-A | 22-04-1041 | 538-22-04-1041 | $0.8900 | $3.56
1 | HW-C2-RES-220-A | 220 1210 | 603-RC1210FR-07220 RL | $0.1000 | $0.10
6 | HW-C2-CAP-220P-A | 220pF 100V C0G 1210 | 80-C1210C221J2G | $0.8800 | $5.28
4 | HW-C2-CAP-22P-A | 22pF 50V | 80-C1210C220J5G | $0.7400 | $2.96
3 | HW-C2-RES-3K-A | 3k 1210 1% | 603-RC1210FR-073KL | $0.1000 | $0.30
3 | HW-C2-RES-4K7-A | 4.7k 1210 | 71-CRCW12104K70F KEAH | $0.5900 | $1.77
3 | HW-C2-HW-455-2266-ND-A | 455-2266-ND | 306-XHP-2 | $0.1000 | $0.30
25 | HW-C2-HW-464762-E-A | 464762-E | 305-464762 | $0.3970 | $9.93
1 | HW-C2-RES-499K-A | 499kohm 1210 resistor | 667-ERJ-P14F4993U | $0.4400 | $0.44
5 | HW-C2-HW-524265-E-A | 524265-E | 305-524265-E | $7.8700 | $39.35
5 | HW-C2-HW-544959-E-A | 544959-E | - | N/A | N/A
2 | HW-C2-RES-560-A | 560ohm 1210 resistor | 667-ERJ-P14F5600U | $0.4400 | $0.88
1 | HW-C2-HW-776231-1-A | 776231-1 | 571-776231-1 | $16.6900 | $16.69
2 | HW-C2-IC-8MHZ-A | 8mhz hc49-4h crystal | 710-830003156B | $0.5000 | $1.00
8 | HW-C2-HW-971150581-A | 971150581 | 710-971150581 | $0.6000 | $4.80
8 | HW-C2-HW-971250581-A | 971250581 | 710-971250581 | $1.1000 | $8.80
8 | HW-C2-HW-971350581-A | 971350581 | 710-971350581 | $1.4800 | $11.84
8 | HW-C2-HW-9774030592R -A | 9774030592R | 710-9774030592R | $1.5700 | $12.56
2 | HW-C2-HW-ACT45B-101-2P-TL003-A | ACT45B-101-2P-TL003 | 810-ACT45B1012PTL 003 | $1.5300 | $3.06
2 | HW-C2-HW-AWHSH105D 00G-A | AWHSH105D00G | 523-AWHSH105D00G | $1.1100 | $2.22
3 | HW-C2-HW-B2B-XH-AM_ LF__SN_-A | B2B-XH-AM_LF__SN_ | 306-B2B-XH-AMLFSN P | $0.1000 | $0.30
12 | HW-C2-HW-B58031U9254 M062-A | B58031U9254M062 | 871-B58031U9254M0 62 | $4.6500 | $55.80
12 | HW-C2-HW-BAT54WS-7-F -A | BAT54WS-7-F | 621-BAT54WS-F | $0.1240 | $1.49
5 | HW-C2-HW-BTS462TATM A1-A | BTS462TATMA1 | 726-BTS462TATMA1 | $2.6600 | $13.30
3 | HW-C2-HW-CM600DY-24 T-A | CM600DY-24T | CM600DY-24T | $323.5000 | $970.50
1 | HW-C2-IC-CY15B102Q-S XET-A | CY15B102Q-SXET | 727-CY15B102Q-SXE T | $18.1400 | $18.14

Inverter Gen5 — Chassis2 Hardware Release | 5
Qty | Internal P/N | Description | Part Number | Unit | Total
1 | HW-C2-HW-DRDNB21D-7 -A | DRDNB21D-7 | 621-DRDNB21D-7 | $0.5600 | $0.56
1 | HW-C2-HW-EC7BW-110S 12-A | EC7BW-110S12 | 418-EC7BW-110S12 | $48.8600 | $48.86
12 | HW-C2-HW-FDFNYD1-11 0-5-A | FDFNYD1-110(5) | 161-FDFNYD1-1105 | $0.4800 | $5.76
4 | HW-C2-IC-ISO1042BDWV R-A | ISO1042BDWVR | 595-ISO1042BDWVR | $4.4400 | $17.76
1 | HW-C2-IC-ISO1212DBQ-A | ISO1212DBQ | 595-ISO1212DBQ | $1.7300 | $1.73
4 | HW-C2-HW-LA37S600S05 KM-A | LA37S600S05KM | 838-LA37S600S05KM | $19.9600 | $79.84
1 | HW-C2-HW-LT3080IQ-PB F-A | LT3080IQ#PBF | 584-LT3080IQ#PBF | $8.5400 | $8.54
2 | HW-C2-HW-LTST-C230C KT-A | LTST-C230CKT | 859-LTST-C230CKT | $0.4100 | $0.82
2 | HW-C2-HW-LTST-C230G KT-A | LTST-C230GKT | 859-LTST-C230GKT | $0.3600 | $0.72
1 | HW-C2-IC-MAX22530AW E-A | MAX22530AWE+ | 700-MAX22530AWE+ | $15.6000 | $15.60
1 | HW-C2-HW-MF-RHT200_ 32-2-A | MF-RHT200_32-2 | 652-MF-RHT200/32-2 | $0.6100 | $0.61
6 | HW-C2-HW-MGJ2D12150 9MPC-R7-A | MGJ2D121509MPC-R7 | 580-MGJ2D121509MP CR7 | $6.7700 | $40.62
6 | HW-C2-HW-MKP1848S61 010JY5B-A | MKP1848S61010JY5B | 75-MKP1848S61010J Y5B | $7.5400 | $45.24
5 | HW-C2-HW-MM3Z3V0ST1 G-A | MM3Z3V0ST1G | 863-MM3Z3V0ST1G | $0.1700 | $0.85
6 | HW-C2-IC-NCV57100DW R2G-A | NCV57100DWR2G | 863-NCV57100DWR2 G | $2.9800 | $17.88
1 | HW-C2-HW-NXFT15XH10 3FEAB021-A | NXFT15XH103FEAB021 | 81-NXFT15XH103FEA B21 | $0.3400 | $0.34
1 | HW-C2-HW-RD7-12S033R -A | RD7-12S033R | 737-RD7-12S033R | $6.7700 | $6.77
3 | HW-C2-HW-RKE-1205S_ H-A | RKE-1205S_H | 919-RKE-1205S/H | $5.1700 | $15.51
2 | HW-C2-HW-RTS103C1R2 M6L201-A | RTS103C1R2M6L201 | 527-RTS103C1R2M6L 201 | $2.2700 | $4.54
2 | HW-C2-HW-S3N-A | S3N | 512-S3N | $0.6700 | $1.34
2 | HW-C2-HW-SSW-103-01-L-D-A | SSW-103-01-L-D | 200-SSW10301LD | $1.3400 | $2.68
1 | HW-C2-HW-SSW-104-01-L-D-A | SSW-104-01-L-D | 200-SSW10401LD | $1.6900 | $1.69
2 | HW-C2-HW-SSW-108-01-L-D-A | SSW-108-01-L-D | 200-SSW10801LD | $2.3500 | $4.70
1 | HW-C2-CONN-SSW-110-0 1-F-D-A | SSW-110-01-F-D | 200-SSW11001FD | $2.4100 | $2.41
1 | HW-C2-HW-SSW-110-01-F-D-A | SSW-110-01-F-D | - | N/A | N/A
1 | HW-C2-IC-STM32G474RC T3-A | STM32G474RCT3 | 511-STM32G474RCT3 | $8.3100 | $8.31
1 | HW-C2-IC-STM32H723ZG T6-A | STM32H723ZGT6 | 511-STM32H723ZGT6 | $13.2500 | $13.25

Inverter Gen5 — Chassis2 Hardware Release | 6
Qty | Internal P/N | Description | Part Number | Unit | Total
1 | HW-C2-HW-STS41A-AWL B-R3-A | STS41A-AWLB-R3 | 403-STS41A-AWLB-R 3 | $1.1300 | $1.13
6 | HW-C2-HW-STTH112A-A | STTH112A | 511-STTH112A | $0.5900 | $3.54
6 | HW-C2-HW-SXH-001T-P0 -6-A | SXH-001T-P0.6 | 306-SXH-001T-P0.6 | $0.1000 | $0.60
4 | HW-C2-HW-SZMMSZ4678 T1G-A | SZMMSZ4678T1G | 863-SZMMSZ4678T1 G | $0.4300 | $1.72
21 | HW-C2-HW-TESTPOINT-TH-RED-A | Testpoint TH, RED | 534-5000 | $0.2930 | $6.15
16 | HW-C2-RES-250K-A | Thick Film Resistors - SMD 1/2watt 249Kohms 1% | 71-CRCW1210-249K-E3 | $0.0700 | $1.12
1 | HW-C2-HW-TPS389006A DJRTER-A | TPS389006ADJRTER | 595-TPS389006ADJR TER | $5.1000 | $5.10
2 | HW-C2-HW-TS40-66-50-R -260-SMT-TR-A | TS40-66-50-R-260-SMT-TR | 179-TS406650R260S | $0.4800 | $0.96
2 | HW-C2-HW-TSW-103-18-G-D-A | TSW-103-18-G-D | 200-TSW10318GD | $1.0100 | $2.02
2 | HW-C2-HW-TSW-108-18-F-D-A | TSW-108-18-F-D | 200-TSW10818FD | $1.4500 | $2.90
1 | HW-C2-HW-TSW-110-18-T-D-A | TSW-110-18-T-D | 200-TSW11018TD | $1.5800 | $1.58
1 | HW-C2-CONN-TSW-110-2 1-L-D-LL-A | TSW-110-21-L-D-LL | 200-TSW11021LDLL | $2.2700 | $2.27
13 | HW-C2-HW-UCM1H101M CL1GS-A | UCM1H101MCL1GS | 647-UCM1H101MCL1 GS | $0.3250 | $4.23
60 | HW-C2-HW-UCS2D331M HD-A | UCS2D331MHD | 647-UCS2D331MHD | $2.1600 | $129.60
1 | HW-C2-HW-UJ2-B-HR-G-V-A | UJ2-B-HR-G-V | 179-UJ2-B-HR-G-V | $1.7000 | $1.70
18 | HW-C2-HW-VY1222M47Y 5UQ6TV0-A | VY1222M47Y5UQ6TV0 | 72-VY1222M47Y5UQ6 TV0 | $0.2710 | $4.88
| | | | Subtotal | $1,733.29

# PCB Fabrication

Qty | Internal P/N | Description | Part Number | Unit | Total
1 | HW-C2-PCB-CTRL-A | ControlBoard | ControlBoard | $25.2400 | $25.24
1 | HW-C2-PCB-DCBUSCAP-A | DCBusCapacitorBoard | DCBusCapacitorBoard | $7.5400 | $7.54
1 | HW-C2-PCB-DCFLT-A | DCBusFilter | DCBusFilter | $8.4400 | $8.44
1 | HW-C2-PCB-GD-A | GateDriver | GateDriver | $11.6600 | $11.66
1 | HW-C2-PCB-IO-A | IOBoard | IOBoard | $11.6600 | $11.66
| | | | Subtotal | $64.54

# SendCutSend

Qty | Internal P/N | Description | Part Number | Unit | Total
1 | HW-C2-PLT-BSP-A | HW-C2-BSP-A | HW-C2-BSP-A | $144.4600 | $144.46
1 | HW-C2-PLT-CHSP-A | HW-C2-CHSP-A | HW-C2-CHSP-A | $24.6700 | $24.67

Inverter Gen5 — Chassis2 Hardware Release | 7
Qty | Internal P/N | Description | Part Number | Unit | Total
2 | HW-C2-BB-DCLBB-A | HW-C2-DCLBB-A | HW-C2-DCLBB-A | $45.1200 | $90.24
3 | HW-C2-BB-PBB-A | HW-C2-PBB-A | HW-C2-PBB-A | $17.0300 | $51.09
| | | | Subtotal | $310.46

Inverter Gen5 — Chassis2 Hardware Release | 8

# Cost by Assembly

Assembly | Kind | Qty/chassis | Parts | Cost (1 unit)
PCB assembly: Control Board | PCB assembly | 1 | 43 | $210.39
PCB assembly: DC Bus Capacitor Board | PCB assembly | 1 | 2 | $149.70
PCB assembly: Filter Board | PCB assembly | 1 | 4 | $122.23
PCB assembly: Gate Driver Board | PCB assembly | 1 | 22 | $138.47
PCB assembly: IO Board | PCB assembly | 1 | 15 | $105.24
chassis hardware: Mechanical | chassis hardware | 1 | 13 | $1,118.82
Capacitor Temp Sense Wiring Harness | wiring harness | 1 | 3 | $0.64
Current Sensor Wiring Harness | wiring harness | 4 | 3 | $79.84
Gate Drive Wiring Harness | wiring harness | 1 | 3 | $15.69
IGBT Temperature Wiring Harness | wiring harness | 2 | 3 | $5.14
fabricated part: Fab | fabricated part | 1 | 1 | $144.46
fabricated part: Fab | fabricated part | 1 | 1 | $24.67
fabricated part: Fab | fabricated part | 2 | 1 | $90.24
fabricated part: Fab | fabricated part | 3 | 1 | $51.09
| | | Total | $2,256.61

Costs are per-piece at current prices (pack prices divided out); assembly labor and PCB fab quantities at other build counts follow the pack math in the vendor sections.

Inverter Gen5 — Chassis2 Hardware Release | 9

# Fabrication Package

Item | Kind | Qty | Rev | Price | Ready
ControlBoard | PCB | 1 | A | $25.24 | yes
DCBusCapacitorBoard | PCB | 1 | A | $7.54 | yes
DCBusFilter | PCB | 1 | A | $8.44 | yes
GateDriver | PCB | 1 | A | $11.66 | yes
IOBoard | PCB | 1 | A | $11.66 | yes
HW-C2-BSP-A | fab part | 1 | A | $144.46 | yes
HW-C2-CHSP-A | fab part | 1 | A | $24.67 | yes
HW-C2-DCLBB-A | fab part | 2 | A | $45.12 | yes
HW-C2-PBB-A | fab part | 3 | A | $17.03 | yes
CapacitorTempSenseHarness | harness | 1 | A | - | yes
CurrentSenseHarness | harness | 4 | A | - | yes
GDVSHarness | harness | 1 | A | - | yes
TempSenseHarness | harness | 2 | A | - | yes

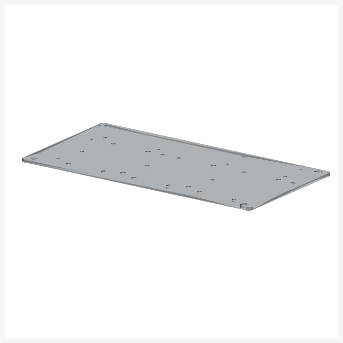
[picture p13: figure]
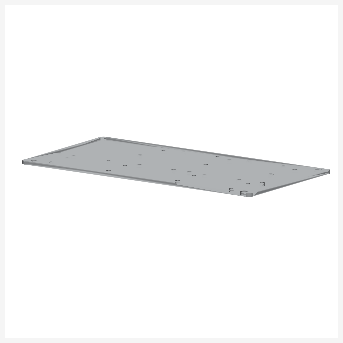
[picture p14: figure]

Inverter Gen5 — Chassis2 Hardware Release | 10

# HW-C2-BSP-A

## 6061 T6 Aluminum / 9.52 mm / Sheet Cutting / Deburring, Tapping

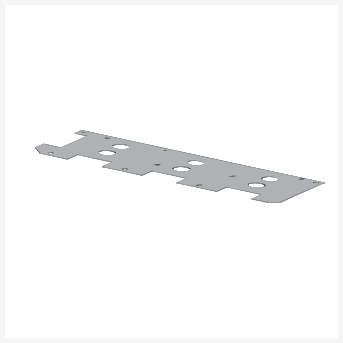
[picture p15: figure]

Inverter Gen5 — Chassis2 Hardware Release | 11

# HW-C2-CHSP-A

## 6061 T6 Aluminum / 3.17 mm / Sheet Cutting / Deburring

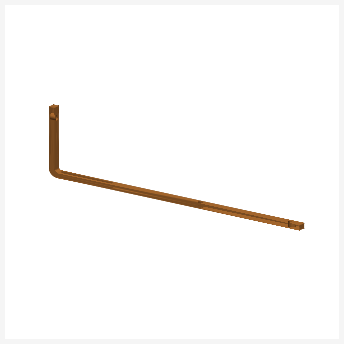
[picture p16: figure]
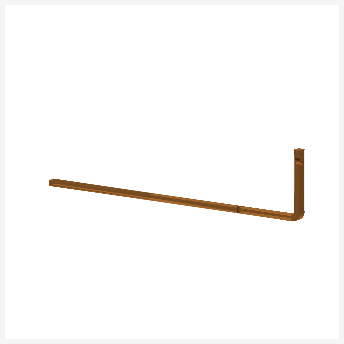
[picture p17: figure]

Inverter Gen5 — Chassis2 Hardware Release | 12

# HW-C2-DCLBB-A

## Copper / 4.75 mm / Sheet Cutting / Bending

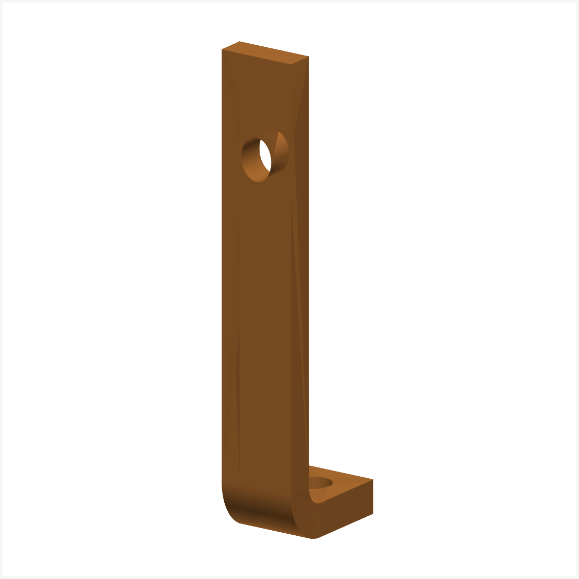
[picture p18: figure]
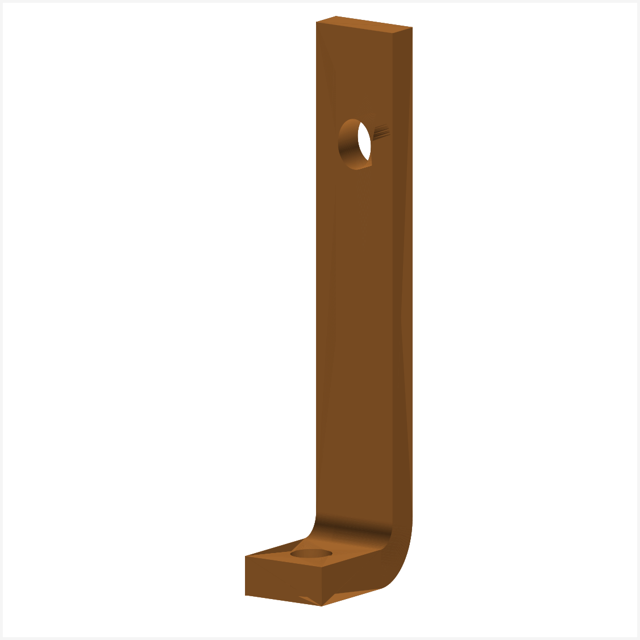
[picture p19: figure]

Inverter Gen5 — Chassis2 Hardware Release | 13

# HW-C2-PBB-A

## Copper / 4.75 mm / Sheet Cutting / Bending

# PCB ASSEMBLY: CONTROL BOARD

## HW-C2-PCB-CTRL-A · printed circuit board — schematic and PCB layers

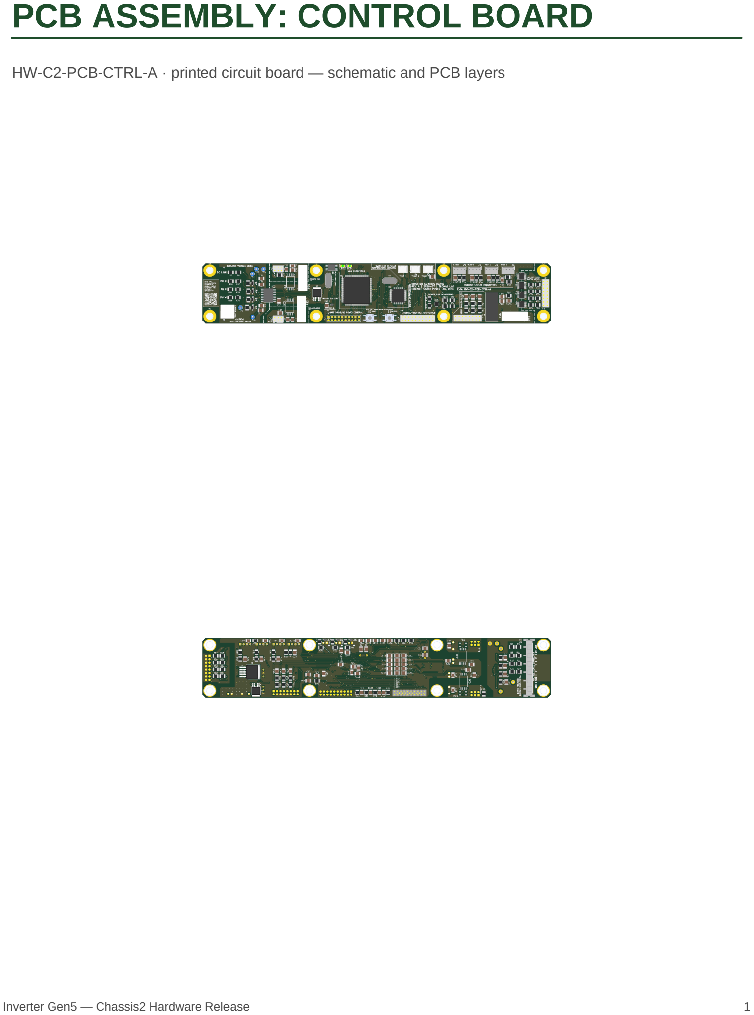
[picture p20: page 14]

Inverter Gen5 — Chassis2 Hardware Release | 1

1 | 2 | 3 | 4 | 5
1 | 2 | 3 | 4 | 5

AB

C

D

AB

C

D Date: 2026-07-07

KiCad E.D.A. 10.0.3

Size: USLetter | Rev: A Id: 1/21

## Title: Open Inverter Platform - Control Board

File: ControlBoard.kicad_sch

Sheet: /

Corzine Lab, University of California, Santa Cruz

Prepared by Thomas Liao

HW-C2-PCB-CTRL GND

SIG1_IN SIG1_OUT SIG2_IN SIG2_OUT SIG3_IN SIG3_OUT SIG4_IN SIG4_OUT

Voltage Divider Network1

File: VDivNet.kicad_sch | +3.3V_A DIN_1_A DIN_1_B DIN_2_A DIN_2_B DIN_3_A DIN_3_B DIN_4_A DIN_4_B DIN_5_A DIN_5_B DIN_6_A DIN_6_B DIN_7_A DIN_7_B DIN_8_A DIN_8_B

GND_A GND_B

Isolated Digital IO

File: IsolatedDigitalIO.kicad_sch GND

SIG1_IN SIG1_OUT SIG2_IN SIG2_OUT SIG3_IN SIG3_OUT SIG4_IN SIG4_OUT

Voltage Divider Network File: VDivNet.kicad_sch GND_A +3.3V_OUT_A +12V_OUT_A +5V_A | +12V_IN +12V_SWITCHED_A SIGNAL_12V_ENABLE_A +12V_CANBUS_A CANBUS_12V_ENABLE_A Power File: Power.kicad_sch | +¹²V_A +³.3V_A CAN_L_B CAN_H_B CAN_GND CAN_5V | CAN_JUMPER_A CAN_JUMPER_B GND_A B_CAN_TX B_CAN_RX A_CAN_TX A_CAN_RX CAN Transciever1 | File: CANTransciever.kicad_sch | +3.3V_A GND_A SPI_SCK_A

ADC1_CS_A VSENSE_DC_LINK_B

VSENSE_GND_B

VSENSE_PH_U_B

VSENSE_PH_V_B

VSENSE_PH_W_B

ADC1_INT_A SPI_MISO_A SPI_MOSI_A

ADC

File: ADC2.kicad_sch GND

SIG1_IN SIG1_OUT SIG2_IN SIG2_OUT SIG3_IN SIG3_OUT SIG4_IN SIG4_OUT

Voltage Divider Network2

File: VDivNet.kicad_sch | +¹²V_A +³.3V_A CAN_L_B CAN_H_B CAN_GND CAN_5V | CAN_JUMPER_A CAN_JUMPER_B GND_A B_CAN_TX B_CAN_RX A_CAN_TX A_CAN_RX CAN Transciever | File: CANTransciever.kicad_sch

GND

SIG1_IN SIG1_OUT SIG2_IN SIG2_OUT Voltage Divider Network3
File: VDivNetHalf.kicad_sch | +3.3V_A GND_A GND_ANALOG_A | CP_BOOT_SEL CP_DEBUG_JTCK_SWCLK CP_DEBUG_JTMS_SWDIO CP_FDCAN2_TX CP_FDCAN2_RX | CP_FDCAN3_TX CP_FDCAN3_RX | CP_GATE_DRIVE_PWR2_ENABLE CP_RESET | CP_USB_DM
CP_USB_DP MP_BOOT_SEL | MP_CANBUS_12V_POWER_ENABLE MP_DEBUG_JTCK_SWCLK MP_DEBUG_JTCK_SWDIO MP_DEBUG_NJTRST MP_DEBUG_SWO MP_DEBUG_TRGIO MP_FDCAN2_TX MP_FDCAN2_RX | MP_FDCAN1_TX MP_FDCAN1_RX | MP_GATE_DRIVE_PWR1_ENABLE MP_PERIPHERAL_POWER_ENABLE MP_RESET | MP_SPI2_CS MP_SPI2_MISO MP_SPI2_MOSI MP_SPI2_SCK MP_TEMP_SENSE_2 MP_TEMP_SENSE_3 | MP_USER_DIN_5 MP_USER_DIN_6 MP_USER_DIN_7 MP_USER_DIN_8 MP_USER_DOUT_1 MP_USER_DOUT_2 MP_USER_DOUT_3 MP_USER_DOUT_4 MP_VSENSE_ISO_ADC_INTERRUPT SN_CUR_SENSE_DC_LINK_REF SN_CUR_SENSE_DC_LINK_SIG

SN_CUR_SENSE_PH_U_REF SN_CUR_SENSE_PH_U_SIG

SN_CUR_SENSE_PH_V_REF SN_CUR_SENSE_PH_V_SIG

SN_CUR_SENSE_PH_W_REF SN_CUR_SENSE_PH_W_SIG

SN_GATE_DRIVE_FAULT SN_GATE_DRIVE_PWR2_FB SN_GATE_DRIVE_PWR1_FB | SN_GATE_DRIVE_READY SN_GATE_DRIVE_RESET SN_HALL_U_ENCODER_SIN

SN_HALL_V_ENCODER_COS
SN_HALL_W

SN_MOTOR_TEMP

SN_PH_U_HIGH
SN_PH_U_LOW
SN_PH_V_HIGH
SN_PH_V_LOW
SN_PH_W_HIGH
SN_PH_W_LOW

SN_TEMP_SENSE_1

SN_THROTTLE_A SN_THROTTLE_B | SN_USER_DIN_1 SN_USER_DIN_2 SN_USER_DIN_3 SN_USER_DIN_4 +5V_A +5V_ISENSE_A +12V_A | MULTIDRIVE_FIBER_SYNC MULTIDRIVE_FIBER_UART_RX MULTIDRIVE_FIBER_UART_TX Control File: Control.kicad_sch | GND_V HEATSINK_TMP2_V HEATSINK_TMP3_V HEATSINK_TMP_V | +3.3V_V MOTOR_TEMP_IN MOTOR_TEMP_V

TemperatureSensors File: TemperatureSensors.kicad_sch DC_LINK_CURSENS DC_LINK_CURSENS_REF GND

PH_U_CURSENS PH_U_CURSENS_REF PH_V_CURSENS PH_V_CURSENS_REF PH_W_CURSENS PH_W_CURSENS_REF +12V_A +5V_ISENSE_A Current Sensors File: CurrentSensors.kicad_sch H2 971350581

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
10 | 11
| 12

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
# TSW-110-21-L-D-LL 1

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
6 MP1 7 MP2 8 MP3 9 MP4 10

J15
524265-E

1
2
3
4
5
6
7
8 | 9
| 10

11

12

13

14

15

16

J7
SSW-108-01-L-D

1
2
3 | 4
| 5

6

J13
SSW-103-01-L-D

1
2
3 | 4
| 5

6

J10

SSW-103-01-L-D H5

971350581 H4
971350581

1

2

3

4

5

6

7

8 916151413121110 J12 SSW-108-01-L-D

H6

971350581 H3
971350581 H8

971350581 H7
971350581

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
10 | 11
| 12

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
SSW-110-01-F-D H1
971350581 | PH_W_H

PH_V_H

GND_A GATE_DRIVE_PWR1_FEEDBACK | GATE_DRIVE_PWR2_FEEDBACK GATE_DRIVE_PWR1_FEEDBACK GND_A PH_U_L READY

FAULT DRIVER_RESET PH_V_L PH_U_H

GND_A
FAULT | GATE_DRIVE_PWR1_ENABLE PH_W_L +3.3V_A GND_A | GATE_DRIVE_PWR2_ENABLE GATE_DRIVE_PWR1_ENABLE READY GATE_DRIVE_PWR2_ENABLE | PH_W_H

PH_W_L PH_U_H
PH_V_L PH_U_L PH_V_H
DRIVER_RESET FAULT GND_A GATE_DRIVE_PWR2_FEEDBACK +12V_SWITCHED_A | GND_A_A | GND_A CP_RESET CP_BOOTSEL HALL_W_IN +5V_ISENSE_A | MP_SWO

THROTTLE_B_IN MOTOR_TEMP_IN

GND_A_A

THROTTLE_A_IN | MP_SWCLK MP_SWDIO | MP_SWO | MP_RESET | MD_FIBER_SYNC MD_FIBER_RX MP_RESET MP_BOOTSEL | USB_DM

MD_FIBER_TX USB_DP

GND_A | CP_BOOTSEL +3.3V_A MD_FIBER_RX MD_FIBER_TX | CP_SWCLK CP_SWDIO CP_RESET CP_SWDIO MD_FIBER_SYNC +12V_IN_A MP_SWCLK | CP_SWCLK | CANBUS_ENABLE_12V_A | DIN_2_W | DIN_3_W | DIN_4_W GND_W | GND_W DIN_1_W | GND_W | GND_W DIN_7_W GND_W DIN_6_W GND_W DIN_5_W

USB_DM
USB_DP
GND_A MTR_TMP HS_TMP_2 HS_TMP_1 HS_TMP_3 | GND_A

VS_GND_Y

VS_PH_V_Y

VS_DC_LINK_Y

VS_PH_W_Y +3.3V_A

VS_PH_U_Y ONBOARD_12V_ENABLE_A | +3.3V_A MOTOR_TEMP_IN

GND_A_A DIN_1_W

MP_BOOTSEL GND_A | GND_A +¹²V_CANBUS_A +³.3V_A | DIN_2_W DIN_3_W DIN_4_W DIN_5_W DIN_6_W DIN_7_W DIN_8_W GND_A +¹²V_CANBUS_A | CAN1_HIGH MP_SWDIO | CAN1_GND | CAN1_JUMPER_B CAN1_LOW | CAN1_+⁵V | CAN1_JUMPER_A | DOUT1_A DOUT2_A | GND_W DIN_8_W GND_W
GND_W | DOUT3_A+3.3V_A | DOUT4_AVS_GND_Y
VS_PH_U_Y

VS_PH_W_Y

# VS_DC_LINK_Y +12V_CANBUS_A

HALL_W_IN

GND_A | +12V_IN_A CANBUS_ENABLE_12V_A ONBOARD_12V_ENABLE_A CAN2_JUMPER_B VS_PH_V_Y | CAN2_JUMPER_A

# VS_GND_Y +12V_A +3.3V_A +5V_A

HALL_U_ENCODER_SIN_IN

HALL_V_ENCODER_COS_IN | +12V_A | HS_TMP_3 HS_TMP_1 GND_A HALL_U_ENCODER_SIN_IN
GND_A HALL_V_ENCODER_COS_IN +5V_A GND_A_A | +12V_A +5V_A GND_A +3.3V_A MOTOR_TEMP_IN +12V_SWITCHED_A
GND_A +5V_ISENSE_A | DOUT3_A DOUT2_A DOUT4_A DOUT1_A GND_A

THROTTLE_A_IN

GND_A

THROTTLE_B_IN

GND_A_A | CAN2_GND CAN2_+⁵V | CAN2_JUMPER_B CAN2_LOW
CAN1_HIGH | CAN2_HIGH

CAN2_HIGH
CAN2_LOW
GND_A_A | HS_TMP_2 | CAN2_GND | CAN2_JUMPER_A GND_A_A | +³.3V_A CAN1_+5V | CAN1_LOW

CAN1_JUMPER_A CAN2_+5V CAN1_JUMPER_B

CAN1_GND

This design has been implemented to provide multiple redundant pathways to SSO (Six-switch off) / STO (Safe torque-off). SSO/STO

is the default safe-state of the inverter please (see Hazard And Risk Assessment documentation)

Additionally, while best effort has been made to implement functional safety best practices, please note that no formal independent review has taken place, and therefore no formal ASIL/SIL compliance is claimed. NOTE: WHEN NOT IN FIBER MULTIDRIVE MULTIPHASE OR LOAD SHARING OPERATION, DISABLE TIM1 SYNC PIN (TIM1 ETR) Connector from gate drivers

Includes multiple redundant SSO (six-switch-off) pathways: - via gate drive reset - via gate drive power enable 1 - via gate drive power enable 2

(Gate driver power enable
implemnts 1oo2, with monitoring feedback). feedback pins are 0-3.3v binary
(3.3v expected when +12v present) | Connector to IO board Digital Outputs provided here to IOBoard. | Connector to IO board Control system has dual independent mcus, targeting ASIL decomposition.

Independently monitored switching commands, current responses, canbus commands + faults Please see HARA under documentation for additional informaton. CONNECTOR FROM THIS GATE DRIVER TO MAIN CONTROL BOARD BELOW

onboard power regulator section, for 3.3v mcu power, +5v current sense, etc

SINGLE WIRE DEBUG / PROGRAMMING USB INTERFACE TO TOP IO BOARD +12V TO CTRL BOARD FROM IO BOARD voltage sense connector ISOLATED, HIGH VOLTAGE! | Connector to IO board Provides dual fully isolated canbus interfaces
(isolated from each-other as well) J13 | 60v tolerant SSW-103-01-L-D

1
2
3 | 4

5

6

J10
SSW-103-01-L-D
1
2
3 | 4
| 5

6

HW-C2-PCB-CTRL
Prepared by Thomas Liao
Corzine Lab, University of California, Santa Cruz
Sheet: /ADC/
File: ADC2.kicad_sch
Title: Open Inverter Platform - Control Board
KiCad E.D.A. 10.0.3

ZENER CLAMPS ADC INPUT AT 1.8V
ADC MAX INPUT IS 1.8V ON SENSE PINS

HW-C2-PCB-CTRL
Prepared by Thomas Liao
Corzine Lab, University of California, Santa Cruz
Sheet: /ADC/VoltageSenseInputStage/
File: VoltageSenseInputStage.kicad_sch
Title: Open Inverter Platform - Control Board
KiCad E.D.A. 10.0.3

250k Z3

ADC MAX INPUT IS 1.8V ON SENSE PINS R19

ZENER CLAMPS ADC INPUT AT 1.8V

HW-C2-PCB-CTRL
Prepared by Thomas Liao
Corzine Lab, University of California, Santa Cruz
Sheet: /ADC/VoltageSenseInputStage1/
File: VoltageSenseInputStage.kicad_sch
Title: Open Inverter Platform - Control Board
KiCad E.D.A. 10.0.3

ZENER CLAMPS ADC INPUT AT 1.8V
ADC MAX INPUT IS 1.8V ON SENSE PINS

HW-C2-PCB-CTRL
Prepared by Thomas Liao
Corzine Lab, University of California, Santa Cruz
Sheet: /ADC/VoltageSenseInputStage2/
File: VoltageSenseInputStage.kicad_sch
Title: Open Inverter Platform - Control Board
KiCad E.D.A. 10.0.3

250k Z1

ADC MAX INPUT IS 1.8V ON SENSE PINS R3

ZENER CLAMPS ADC INPUT AT 1.8V

HW-C2-PCB-CTRL
Prepared by Thomas Liao
Corzine Lab, University of California, Santa Cruz
Sheet: /ADC/VoltageSenseInputStage3/
File: VoltageSenseInputStage.kicad_sch
Title: Open Inverter Platform - Control Board
KiCad E.D.A. 10.0.3

two can transcievers, allows safety coproc to snoop and interact with can traffic, if needed. provides redundant path to read and cross-check motor torque commands, if using canbus for torque cmd over throttle A/B inpts Close Jumper if terminating node

HW-C2-PCB-CTRL
Prepared by Thomas Liao
Corzine Lab, University of California, Santa Cruz
Sheet: /CAN Transciever1/
File: CANTransciever.kicad_sch
Title: Open Inverter Platform - Control Board
KiCad E.D.A. 10.0.3

# 100nFSDA 1 SCL 2 VDD

# SN_THROTTLE_A MP_RESET SN_USER_DIN_2

bus for Distributed Drive Communication (DDC). IO Board will need to be variant that has fiber in and out Enables power stage parallel operation or 6+ phase drives. PREFIX NAMING CONVENTION:
MP_ -> Main Processor
CP_ -> Co-Processor

reset switch, push to reset

Inter-mcu UART also runs challenge/response watchdog

desat + redundant adc current sense determined to be acceptable Safe Torque Off can be achieved within 100mS without OCP comparators Both STM MCUs have hw analog watchdogs that achieve the same function Safety coprocessor added as intent to target ASIL B⁽D⁾ + ASIL B⁽D⁾ Note: ASIL-B requires STM's SIL library which we cannot include here ⁽propreitary⁾ As such, this makes the approach a best-effort attempt. Additionally, no formal safety analysis by an independent agency has been performed.

For multidrive operation, hardware supports fiber ring

Power Supply Monitor File: PowerSupplyMonitor.kicad_sch +3.3V_A DC_LINK_CURRENT_REF_N

hw ocp not needed, see HARA for addt'l info

Independently monitors and can trigger fault on power brownout Solves risk of common power rail to Main MCU + Safety Coproc causing failure in both

Power monitoring, SIL-3 compliant system

Prepared by Thomas Liao
Corzine Lab, University of California, Santa Cruz
Sheet: /Control/
File: Control.kicad_sch
Title: Open Inverter Platform - Control Board
KiCad E.D.A. 10.0.3

100nF-

100nF-

HW-C2-PCB-CTRL
Prepared by Thomas Liao
Corzine Lab, University of California, Santa Cruz
Sheet: /Control/Hardware Overcurrent Detection/
File: HWOCP.kicad_sch
Title: Open Inverter Platform - Control Board
KiCad E.D.A. 10.0.3

# 100nFC33

HW-C2-PCB-CTRL
Prepared by Thomas Liao
Corzine Lab, University of California, Santa Cruz
Sheet: /Control/Safety Coprocessor/
File: SafetyCoprocessor.kicad_sch
Title: Open Inverter Platform - Control Board
KiCad E.D.A. 10.0.3

# 100nF C136 1uF C135 100nF C26

HW-C2-PCB-CTRL
Prepared by Thomas Liao
Corzine Lab, University of California, Santa Cruz
Sheet: /Control/Main Processor/
File: MainMCU.kicad_sch
Title: Open Inverter Platform - Control Board
KiCad E.D.A. 10.0.3

10k R100

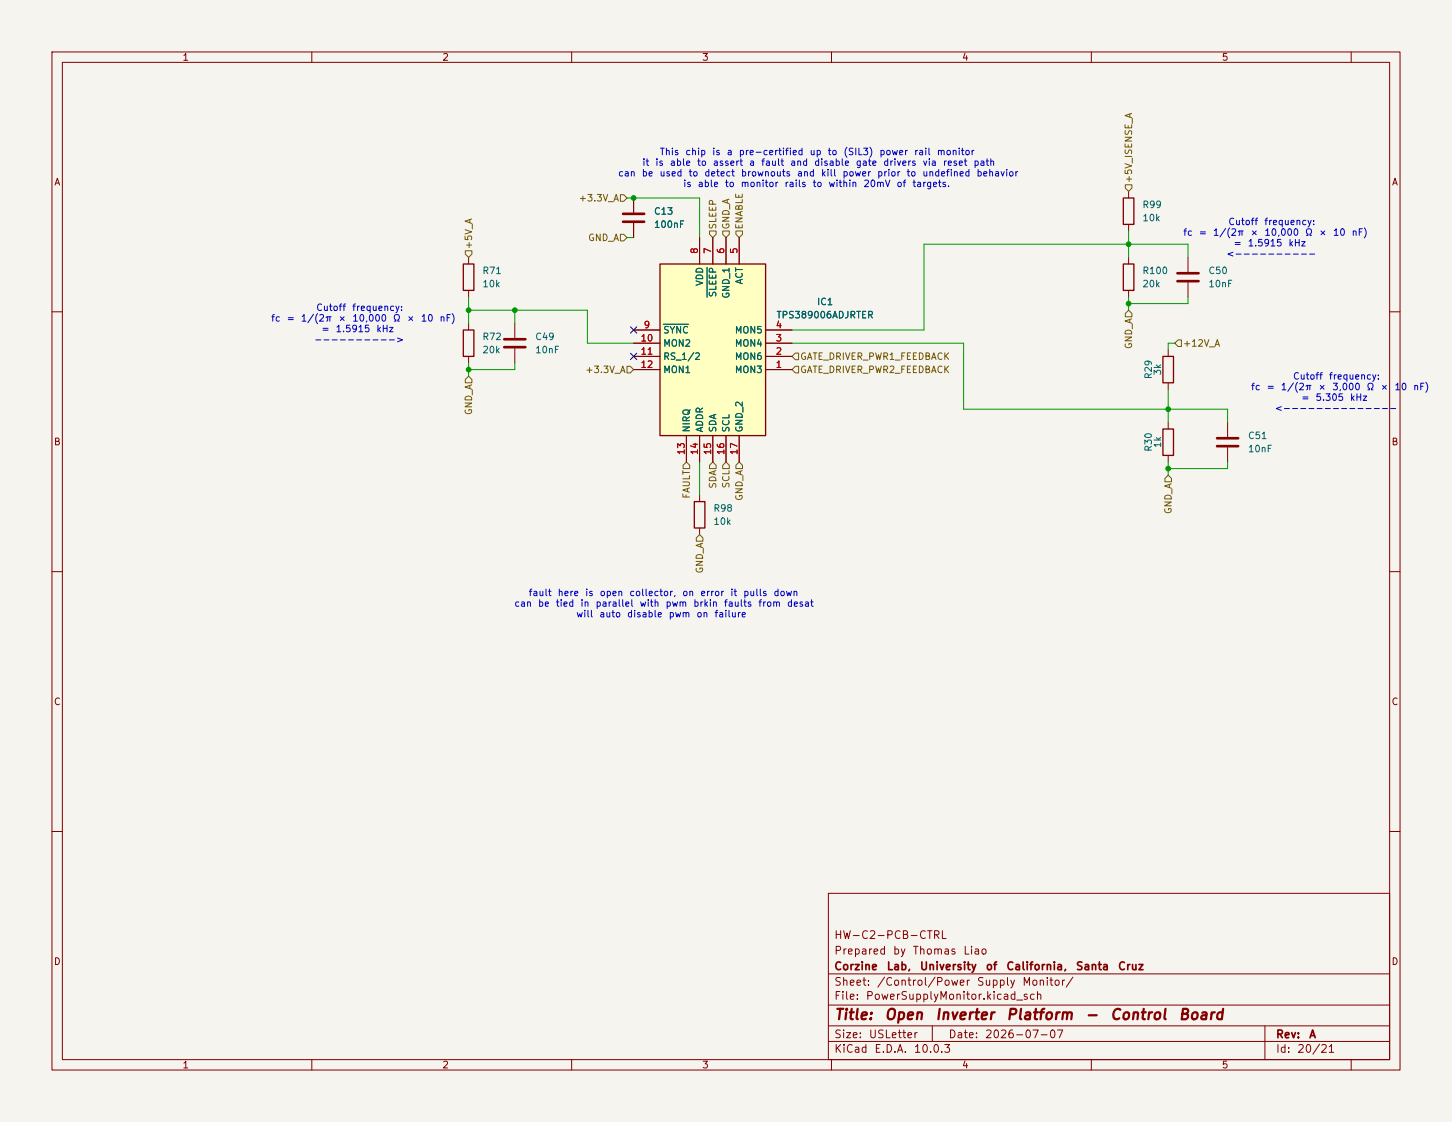
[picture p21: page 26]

This chip is a pre-certified up to (SIL3) power rail monitor
it is able to assert a fault and disable gate drivers via reset path
can be used to detect brownouts and kill power prior to undefined behavior

can be tied in parallel with pwm brkin faults from desat will auto disable pwm on failure C13

Cutoff frequency: fc = 1/(2π × 10,000 Ω × 10 nF) = 1.5915 kHz <----------

Cutoff frequency: fc = 1/(2π × 10,000 Ω × 10 nF) = 1.5915 kHz ---------->

fault here is open collector, on error it pulls down

Prepared by Thomas Liao
Corzine Lab, University of California, Santa Cruz
Sheet: /Control/Power Supply Monitor/
File: PowerSupplyMonitor.kicad_sch
Title: Open Inverter Platform - Control Board
KiCad E.D.A. 10.0.3

power enable switch for external +12v aux pwr only enabled when gate drive is disabled due to power constraints can be used to power external aux loads while main system power is off Canbus +12v enable when disabled, canbus transciever secondary sides are not powered

additionally, canbus1 and 2 +5v rails are not present onboard +5v rail

Prepared by Thomas Liao
Corzine Lab, University of California, Santa Cruz
Sheet: /Power/
File: Power.kicad_sch
Title: Open Inverter Platform - Control Board
KiCad E.D.A. 10.0.3

1 | 2 | 3 | 4 | 5
1 | 2 | 3 | 4 | 5

AB

C

D

AB

C

D Date: 2026-07-07

KiCad E.D.A. 10.0.3

Size: USLetter | Rev: A Id: 9/21

## Title: Open Inverter Platform - Control Board

File: TemperatureSensors.kicad_sch

Sheet: /TemperatureSensors/

Corzine Lab, University of California, Santa Cruz

Prepared by Thomas Liao

HW-C2-PCB-CTRL

1

1
2

2

J5 B2B-XH-AM_LF__SN_

1 2 Z5 MM3Z3V0ST1G

R95
1k

1 2 Z8 MM3Z3V0ST1GR90

10k | R91
1k | R97
1k R96
10k | C211

10uF C208

10uF R92

10k 1

1
2

2

# J4 B2B-XH-AM_LF__SN_ 1

1
2

2

J1 B2B-XH-AM_LF__SN_ | R93
1k | C209
10uF ¹ 2 | Z6 MM³Z3V0ST1G

R94

10k 1 2 | Z7 MM³Z3V0ST1G | C210

10uF

GND_V | GND_V GND_V | HEATSINK_TMP2_V GND_V +3.3V_V +3.3V_V +3.3V_V GND_V | GND_V GND_V | HEATSINK_TMP3_V

MOTOR_TEMP_V GND_V

HEATSINK_TMP_V | +3.3V_V GND_V MOTOR_TEMP_IN GND_V | GND_V | 10K thermistor from motor

if using different value thermistor, adjust resistor accordingly For 10k NTC thermistor NOTE: Tempsense 1,2,3 are intended for monitoring IGBT module 1,2,3

system uses 2oo3 voting to exclude outlier temperature as unlikely HARA determines SSO/STO potentially more dangerous to use 1oo3 vs 2oo3 | RC filter gives a bandwidth of ~16Hz HARA determines 16hz is acceptable. fc = 1/(2π × 1,000 Ω × 10 μF) = 15.915 Hz RC filter gives a bandwidth of ~16Hz HARA determines 16hz is acceptable. fc = 1/(2π × 1,000 Ω × 10 μF) = 15.915 Hz RC filter gives a bandwidth of ~16Hz HARA determines 16hz is acceptable. fc = 1/(2π × 1,000 Ω × 10 μF) = 15.915 Hz

tie other end of motor thermistor to gnd_v 10k THERMISTOR CONNECTOR

3v zener, clamps below 3.6v max input to STM32

3v zener, clamps below 3.6v max input to STM32 ¹⁰k THERMISTOR CONNECTOR

3v zener, clamps below 3.6v max input to STM32 | RC filter gives a bandwidth of ~16Hz HARA determines 16hz is acceptable. fc = 1/(2π × 1,000 Ω × 10 μF) = 15.915 Hz 10k THERMISTOR CONNECTOR

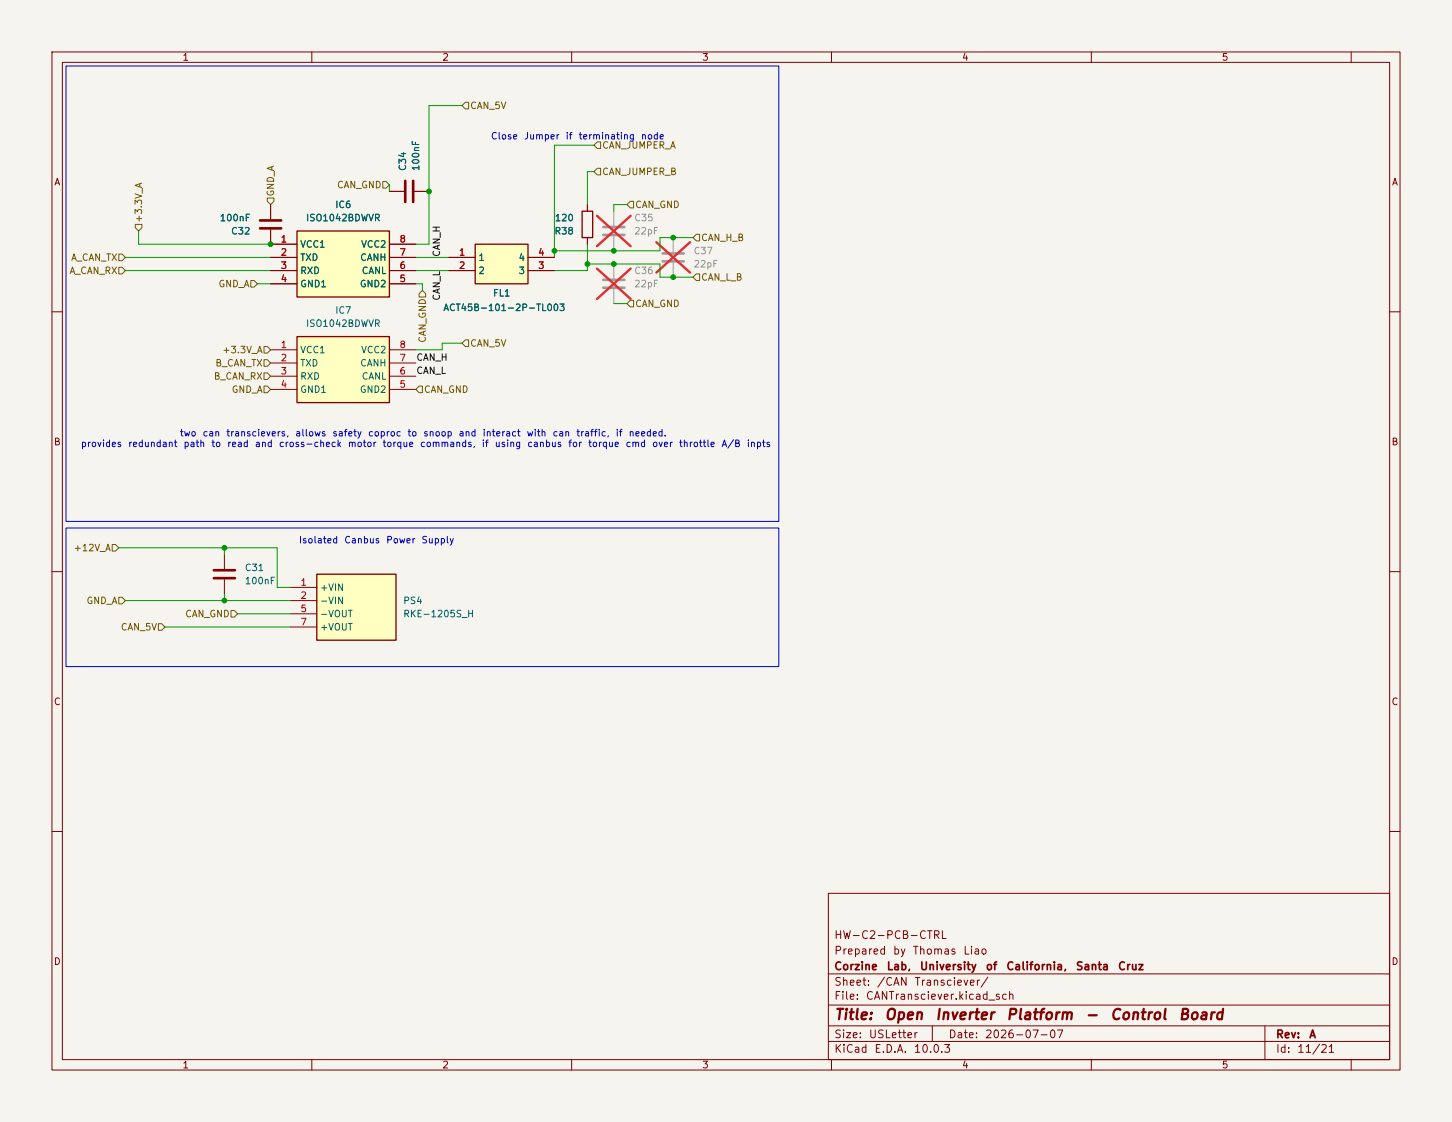
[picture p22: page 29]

two can transcievers, allows safety coproc to snoop and interact with can traffic, if needed. provides redundant path to read and cross-check motor torque commands, if using canbus for torque cmd over throttle A/B inpts Close Jumper if terminating node

HW-C2-PCB-CTRL
Prepared by Thomas Liao
Corzine Lab, University of California, Santa Cruz
Sheet: /CAN Transciever/
File: CANTransciever.kicad_sch
Title: Open Inverter Platform - Control Board
KiCad E.D.A. 10.0.3

20k R51

HW-C2-PCB-CTRL
Prepared by Thomas Liao
Corzine Lab, University of California, Santa Cruz
Sheet: /Voltage Divider Network1/
File: VDivNet.kicad_sch
Title: Open Inverter Platform - Control Board
KiCad E.D.A. 10.0.3

20k R43

HW-C2-PCB-CTRL
Prepared by Thomas Liao
Corzine Lab, University of California, Santa Cruz
Sheet: /Voltage Divider Network/
File: VDivNet.kicad_sch
Title: Open Inverter Platform - Control Board
KiCad E.D.A. 10.0.3

20k R59

HW-C2-PCB-CTRL
Prepared by Thomas Liao
Corzine Lab, University of California, Santa Cruz
Sheet: /Voltage Divider Network2/
File: VDivNet.kicad_sch
Title: Open Inverter Platform - Control Board
KiCad E.D.A. 10.0.3

20k R63

HW-C2-PCB-CTRL
Prepared by Thomas Liao
Corzine Lab, University of California, Santa Cruz
Sheet: /Voltage Divider Network3/
File: VDivNetHalf.kicad_sch
Title: Open Inverter Platform - Control Board
KiCad E.D.A. 10.0.3

100nF 1

HW-C2-PCB-CTRL
Prepared by Thomas Liao
Corzine Lab, University of California, Santa Cruz
Sheet: /Current Sensors/
File: CurrentSensors.kicad_sch
Title: Open Inverter Platform - Control Board
KiCad E.D.A. 10.0.3

# EN 3 OUT1 4 OUT2 5

# EN 3 OUT1 4 OUT2 5

digital input 1-4 are mirrored to safety coprocessor allows for redundant monitoring of safety critical inputs
EN 3 OUT1 4 OUT2 5

(e-stop/kill switch, throttle/torque off limit switch, etc)

Prepared by Thomas Liao
Corzine Lab, University of California, Santa Cruz
Sheet: /Isolated Digital IO/
File: IsolatedDigitalIO.kicad_sch
Title: Open Inverter Platform - Control Board
KiCad E.D.A. 10.0.3

GATE DRIVE/GD POWER CONTROL MAIN PROCESSOR

SCAN FOR
DOCUMENTATION, SCHEMATICS, LAYOUT, BILL OF MATERIALS, AND

INVERTER CONTROL BOARD
REV. A | 2026-07 | THOMAS LIAO
CORZINE SMART POWER LAB, UCSCP/N: HW-C2-PCB-CTRL-A

DEBUG/FIBER MULTIDRIVE/USB

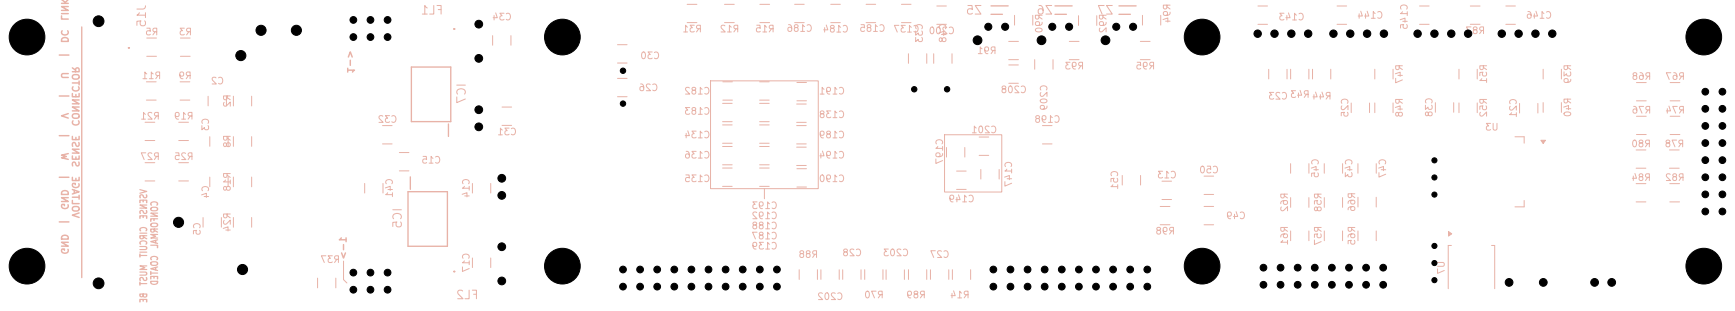
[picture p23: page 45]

VSENSE CIRCUIT MUST BE CONFORMAL COATED 1-> VOLTAGE SENSE CONNECTOR GND | GND | W | V | U | DC LINK 1->R91 C43

Inverter Gen5 — Chassis2 Hardware Release | 1

# DRC — ControlBoard

No DRC errors (warnings suppressed).

# PCB ASSEMBLY: DC BUS CAPACITOR BOARD

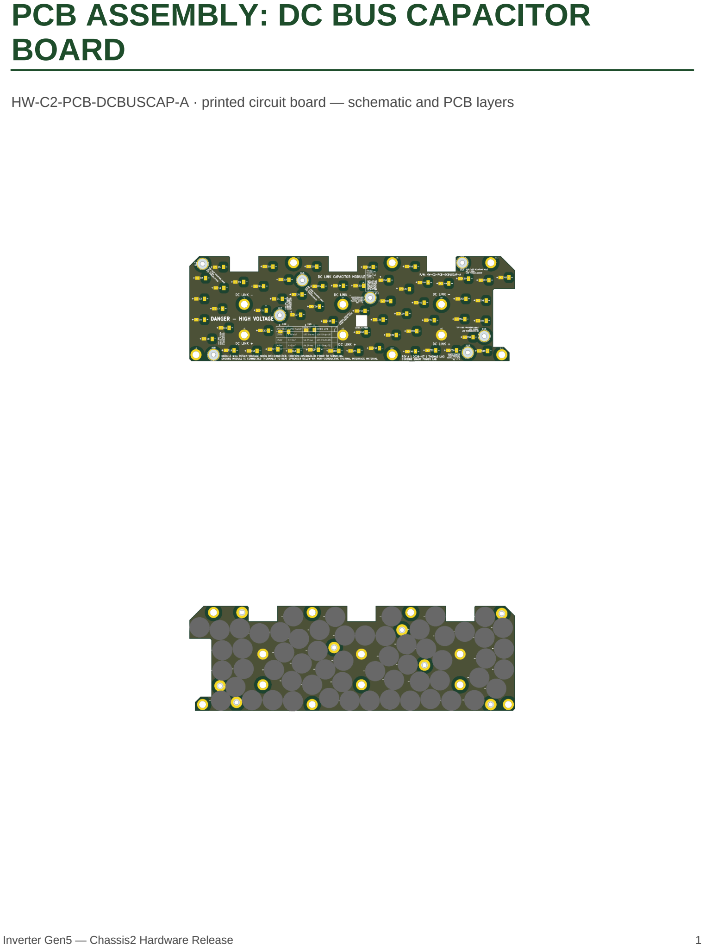
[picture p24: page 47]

Inverter Gen5 — Chassis2 Hardware Release | 1

## HW-C2-PCB-DCBUSCAP-A · printed circuit board — schematic and PCB layers

DC_LINK_- for base plate to board compression, allows assembly to be one module

for top cover mounting

HW-C2-PCB-DCBUSCAP
Prepared by Thomas Liao
Corzine Lab, University of California, Santa Cruz
Sheet: /
File: DCBusCapacitorBoard.kicad_sch
Title: Open Inverter Platform - DC Bus Capacitor Board
KiCad E.D.A. 10.0.3

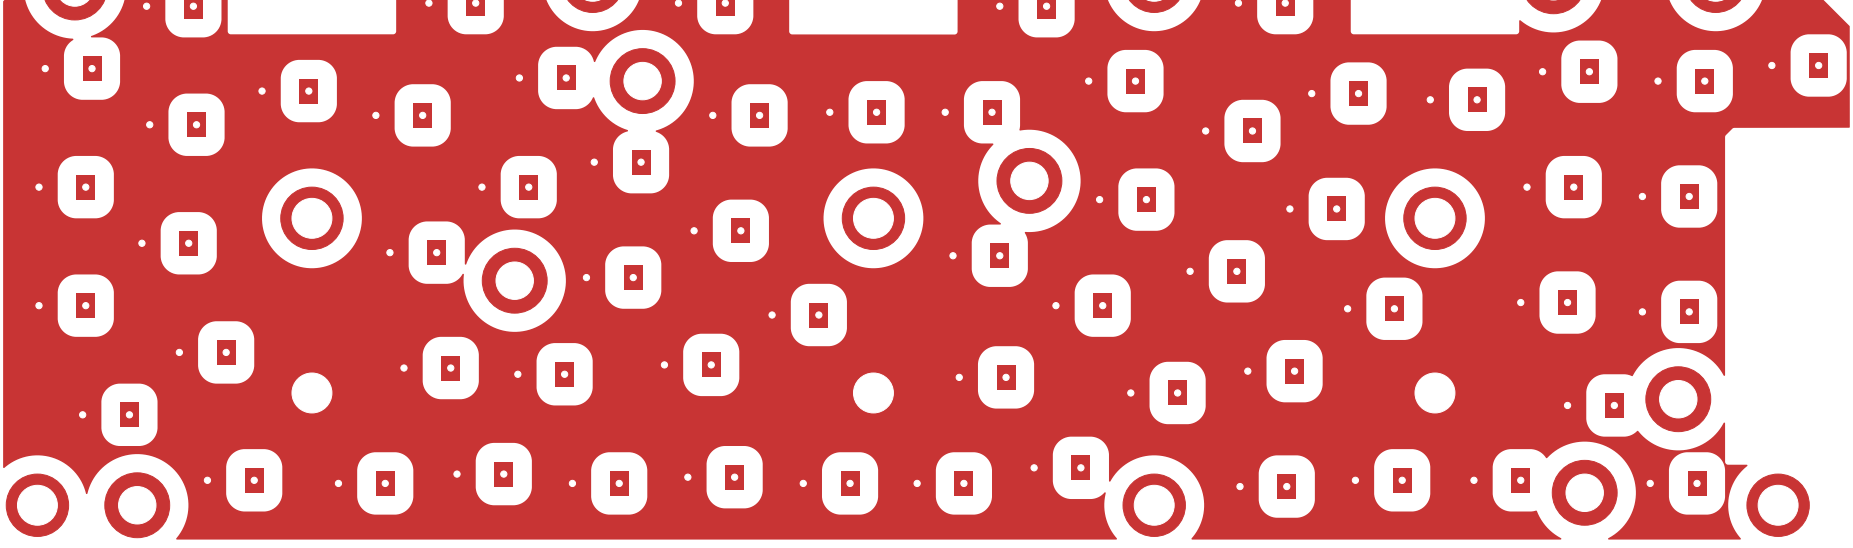
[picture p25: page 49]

DC LINK - | DC LINK - | DC LINK - DANGER - HIGH VOLTAGE

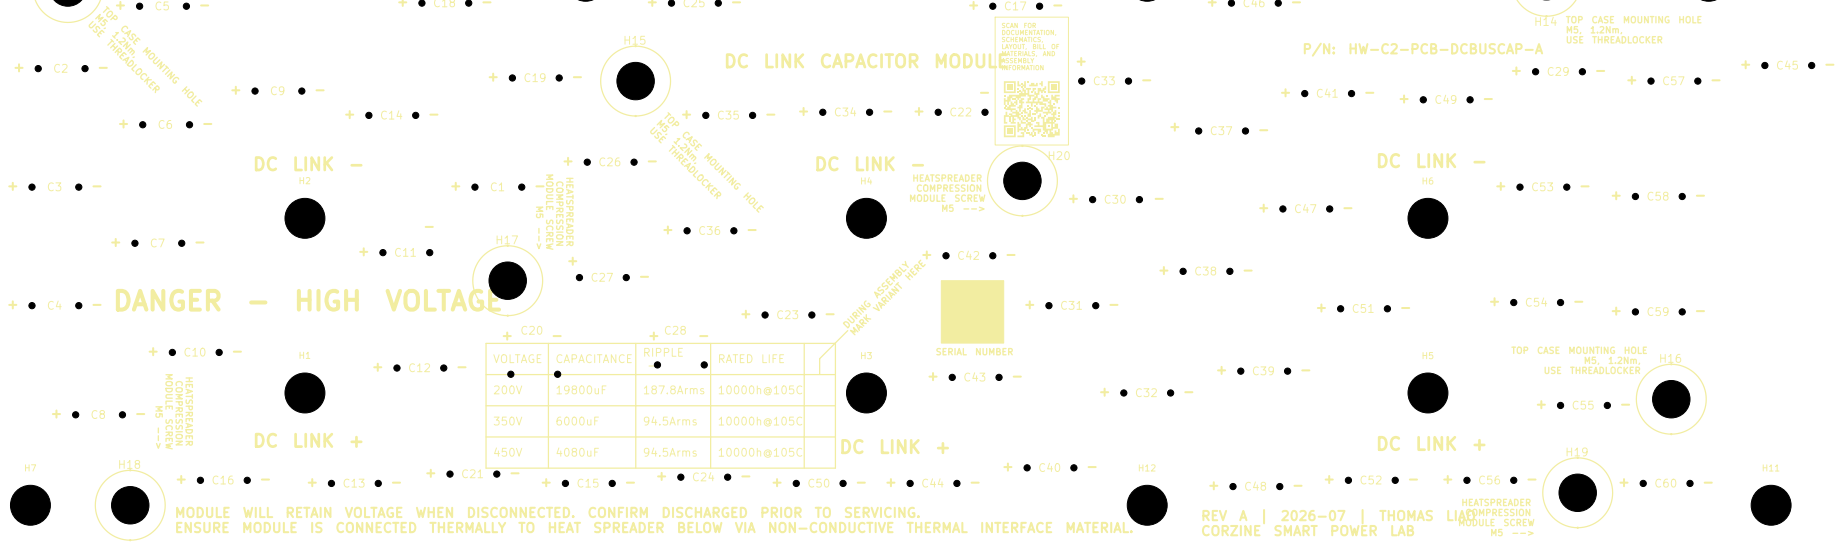
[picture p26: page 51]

TOP CASE MOUNTING HOLE

TOP CASE MOUNTING HOLE M5, 1.2Nm, USE THREADLOCKER HEATSPREADER

SCAN FOR
DOCUMENTATION, SCHEMATICS, LAYOUT, BILL OF MATERIALS, AND

P/N: HW-C2-PCB-DCBUSCAP-A DC LINK CAPACITOR MODULE

MARK VARIANT HERE HEATSPREADER COMPRESSION MODULE SCREW M5 --> HEATSPREADER COMPRESSION MODULE SCREW M5 -->

19800uF | 187.8Arms | RATED LIFE 200V 10000h@105C

TOP CASE MOUNTING HOLE M5, 1.2Nm, USE THREADLOCKER

350V | 6000uF | 94.5Arms | 10000h@105C

450V | 4080uF | 94.5Arms | 10000h@105C

MODULE WILL RETAIN VOLTAGE WHEN DISCONNECTED. CONFIRM DISCHARGED PRIOR TO SERVICING.
ENSURE MODULE IS CONNECTED THERMALLY TO HEAT SPREADER BELOW VIA NON-CONDUCTIVE THERMAL INTERFACE MATERIAL.

REV A | 2026-07 | THOMAS LIAO
CORZINE SMART POWER LAB

Inverter Gen5 — Chassis2 Hardware Release | 1

# DRC — DCBusCapacitorBoard

No DRC errors (warnings suppressed).

# PCB ASSEMBLY: FILTER BOARD

## HW-C2-PCB-DCFLT-A · printed circuit board — schematic and PCB layers

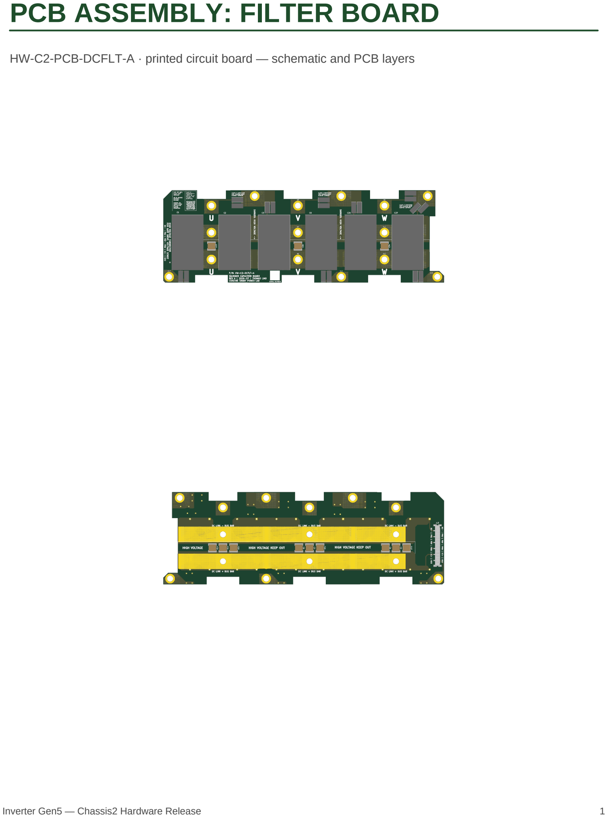
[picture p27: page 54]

Inverter Gen5 — Chassis2 Hardware Release | 1

4 C5 MKP1848S61010JY5BH7 MountingHole_Pad 2 | 1 C21 B58031U9254M062H8 MountingHole_Pad 2 | 1 C22 B58031U9254M062

# CLASS Y SAFETY CAPACITORS PROTECTS BEARINGS DUE TO COMMON MODE EDM PHASE V


LOW INDUCTANCE CERAMIC CAPS <10nH PHASE U

FILM CAPS TO REDUCE dV/dT STRESS ON ELECTROLYTICS CLASS Y SAFETY CAPACITORS PROTECTS BEARINGS DUE TO COMMON MODE EDM

FILM CAPS TO REDUCE dV/dT STRESS ON ELECTROLYTICS

CLASS Y SAFETY CAPACITORS PROTECTS BEARINGS DUE TO COMMON MODE EDM

Prepared by Thomas Liao
Corzine Lab, University of California, Santa Cruz
Sheet: /
File: DCBusFilter.kicad_sch
Title: Open Inverter Platform - Filter Board

62mm IGBT MODULES UP TO 800VDC WORKING

FOR COMMON-MODE BEARING CURRENT SERIAL NUMBER DC- | PHU | PHV | PHW | DC+ | GND

ARE SECURE BEFORE OPERATING

BAR BUS - LINK DC

DC- | PHU | PHV | PHW | DC+ | GND DC- | PHU | PHV | PHW | DC+ | GND

OUT KEEP VOLTAGE HIGH OUT KEEP VOLTAGE HIGH VOLTAGE HIGH C21 C33 C31 C32

BAR BUS + LINK DC

Inverter Gen5 — Chassis2 Hardware Release | 1

# DRC — DCBusFilter

No DRC errors (warnings suppressed).

# PCB ASSEMBLY: GATE DRIVER BOARD

## HW-C2-PCB-GD-A · printed circuit board — schematic and PCB layers


Inverter Gen5 — Chassis2 Hardware Release | 1

# TO MAIN CONTROL BOARD ABOVE GREEN LED FOR +¹²V_A DC/DC INPUT Connector to control board

Includes multiple redundant SSO (six-switch-off) pathways: - via gate drive reset - via gate drive power enable 1 - via gate drive power enable 2

(Gate driver power enable
implemnts 1oo2, with monitoring

PHASE W IGBT DRIVE CONNECTION

CONNECTOR FROM THIS GATE DRIVER

Prepared by Thomas Liao
Corzine Lab, University of California, Santa Cruz
Sheet: /
File: GateDriver.kicad_sch
Title: Open Inverter Platform - Gate Driver Board
KiCad E.D.A. 10.0.3

# +15V_B -9V_B

for other power stages make sure to adjust the gate drive resistors. might need to increase resistance here but perhaps not Observed some ringing on power conns <---

1200v <75nS fast recovery diode When tuning this driver

THIS SHOULD GIVE US ~4uS (Module switches in ~1.2uS)

HW-C2-PCB-GD
Prepared by Thomas Liao
Corzine Lab, University of California, Santa Cruz
Sheet: /SingleChannelDriver1/
File: SingleChannelDriver.kicad_sch
Title: Open Inverter Platform - Gate Driver Board
KiCad E.D.A. 10.0.3

# +15V_B -9V_B

for other power stages make sure to adjust the gate drive resistors. might need to increase resistance here but perhaps not Observed some ringing on power conns <---

1200v <75nS fast recovery diode When tuning this driver

THIS SHOULD GIVE US ~4uS (Module switches in ~1.2uS)

HW-C2-PCB-GD
Prepared by Thomas Liao
Corzine Lab, University of California, Santa Cruz
Sheet: /SingleChannelDriver2/
File: SingleChannelDriver.kicad_sch
Title: Open Inverter Platform - Gate Driver Board
KiCad E.D.A. 10.0.3

# +15V_B -9V_B

for other power stages make sure to adjust the gate drive resistors. might need to increase resistance here but perhaps not Observed some ringing on power conns <---

1200v <75nS fast recovery diode When tuning this driver

THIS SHOULD GIVE US ~4uS (Module switches in ~1.2uS)

HW-C2-PCB-GD
Prepared by Thomas Liao
Corzine Lab, University of California, Santa Cruz
Sheet: /SingleChannelDriver/
File: SingleChannelDriver.kicad_sch
Title: Open Inverter Platform - Gate Driver Board
KiCad E.D.A. 10.0.3

# +15V_B -9V_B

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

1200v <75nS fast recovery diode When tuning this driver

THIS SHOULD GIVE US ~4uS (Module switches in ~1.2uS)

HW-C2-PCB-GD
Prepared by Thomas Liao
Corzine Lab, University of California, Santa Cruz
Sheet: /SingleChannelDriver3/
File: SingleChannelDriver.kicad_sch
Title: Open Inverter Platform - Gate Driver Board
KiCad E.D.A. 10.0.3

# +15V_B -9V_B

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

1200v <75nS fast recovery diode When tuning this driver

THIS SHOULD GIVE US ~4uS (Module switches in ~1.2uS)

HW-C2-PCB-GD
Prepared by Thomas Liao
Corzine Lab, University of California, Santa Cruz
Sheet: /SingleChannelDriver4/
File: SingleChannelDriver.kicad_sch
Title: Open Inverter Platform - Gate Driver Board
KiCad E.D.A. 10.0.3

# +15V_B -9V_B

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

1200v <75nS fast recovery diode When tuning this driver

THIS SHOULD GIVE US ~4uS (Module switches in ~1.2uS)

HW-C2-PCB-GD
Prepared by Thomas Liao
Corzine Lab, University of California, Santa Cruz
Sheet: /SingleChannelDriver5/
File: SingleChannelDriver.kicad_sch
Title: Open Inverter Platform - Gate Driver Board
KiCad E.D.A. 10.0.3

1 | 2 | 3 | 4 | 5
1 | 2 | 3 | 4 | 5

AB

C

D

AB

C

D Date: 2026-07-07

KiCad E.D.A. 10.0.3

Size: USLetter | Rev: A Id: 8/8

## Title: Open Inverter Platform - Gate Driver Board

File: PowerSwitch.kicad_sch

Sheet: /Redundant Monitored Power Switch/

Corzine Lab, University of California, Santa Cruz

Prepared by Thomas Liao

HW-C2-PCB-GD R30 1k R28 3kGND

1

IN 2 | Vbb 3 OUT 5 | U5 BTS462TATMA1 R27 1k | C79

100nF R29 3k 1 2

Z1MM3Z3V0ST1G

R31

120 | GND

1

IN 2 | Vbb 3 OUT 5 | U6 BTS462TATMA1

1 2

Z2MM3Z3V0ST1G

R32

120 C76

100nF | GND_A GATE_DRIVE_PWR2_ENABLE GND_A | GATE_DRIVE_PWR2_FEEDBACK GND_A GND_A | +12V_A GATE_DRIVE_PWR1_FEEDBACK +¹²V_IN GND_A | GND_A GATE_DRIVE_PWR1_ENABLE

Independent gate driver power switch, redundant 1oo2 SSO/STO

Clamp to 3v, below
3.6v stm32 max voltage

cutoff period (1/freq) ->
75.4 uS
acceptable for feedback of power state, de-noises | Cutoff frequency: fc = 1/(2π × 120 Ω × 0.1 μF) = 13,263 Hz Feedback to validate power states Allows Main MCU and Safety coproc to independently monitor and cross-check states of switches | Cutoff frequency: fc = 1/(2π × 120 Ω × 0.1 μF) = 13,263 Hz | Clamp to 3v, below

3.6v stm32 max voltage +12v to 3v voltage divider This circuit implements a redundent pathway for both mcus to implement Six Switch Open / Safe Torque Off in addition to regular pwm break and gate driver reset. The following switches are independent systems with feedback monitoring. Each MCU cross monitors returned inputs, and can validate if the switch

failed to respond as commanded - thus removing latent failures from this safety subsystem. +12v to 3v voltage divider | R31

120

Z1MM3Z3V0ST1G

1 2 R28 3k U5 BTS462TATMA1 GND

1

IN 2 | Vbb 3 OUT 5 | C79
100nF R29 3k | U6 BTS462TATMA1 GND

1

IN 2 Vbb 3 OUT 5

Z2MM3Z3V0ST1G

1 2 R32

120 C76

100nF


SCAN FOR
DOCUMENTATION, SCHEMATICS, LAYOUT, BILL OF MATERIALS, AND

CLAMP, DESAT PROTECTION, REDUNDANT SSO PATHWAYS

Inverter Gen5 — Chassis2 Hardware Release | 1

# DRC — GateDriver

No DRC errors (warnings suppressed).

# PCB ASSEMBLY: IO BOARD

## HW-C2-PCB-IO-A · printed circuit board — schematic and PCB layers


Inverter Gen5 — Chassis2 Hardware Release | 1


BMS CAN1 +5V -> NOTE THIS IS NOT SEVCON PIN COMPATIBLE. DO NOT CONNEC THIS TO SEVCON

IT WILL BLOW UP

BMS CAN1 LOW ->
<- TRACTION BATTERY MINUS TERMINAL BMS CAN1 HIGH ->

<- MOTOR HALL V OR ENCODER COSINE (DEPENDING ON SENSOR TYPE) <- CONNECT TO DC LINK+, ALLOWS INVERTER TO PRECHARGE DC LINK

<- DASH, CHARGER, ABS CANBUS LOW

<- MOTOR THERMISTOR (TIE OTHER END OF THERMISTOR TO GND_A) NOTE TO USER: THEY MUST CONNECT EXTERNAL PRECHARGE RESISTOR

Connector to IO board SINGLE WIRE DEBUG / PROGRAMMING USB INTERFACE TO TOP IO BOARD +12V TO CTRL BOARD FROM IO BOARD

CONNECT SWITCH BETWEEN +12V_A AND THIS PIN ->

BLANK TO ISOLATE TRACTION BATTERY VOLTAGE ->

traction power is not applied when trpwr is on, offboard main power system should power loads instead. <- OUTPUT, TIE TO SEVCON DC/DC ENABLE PIN

USER DIGITAL INPUT 1 (see ctrl board for v/current limits) ->

AUX 12V OUT, TO DISPLAY, KEYSWITCH ->

THROTTLE HOME POSITION SWITCH (REF'D TO THROTTLE +5V) ->

enables/disables aux 12v output.

(FOR FIBER IO MULTIDRIVE MODULE, ETC) ALLOWS MULTI-DRIVE MANY PHASE (>3) OR LOAD SHARING

Note, when system is running, this output must not be on due to power constraints with onboard regulator

intended use case is to run aux systems while

HW-C2-PCB-IO
Prepared by Thomas Liao
Corzine Lab, University of California, Santa Cruz
Sheet: /
File: IOBoard.kicad_sch
Title: Open Inverter Platform - IO Board
KiCad E.D.A. 10.0.3

SEVCON DC/DC ENABLE CIRCUIT


SCAN FOR
DOCUMENTATION, SCHEMATICS, LAYOUT, BILL OF MATERIALS, AND

EXPANSION MODULE SOCKET
SEE DOCUMENTATION FOR AVAILABLE
MODULES AND CONNECTOR PINOUT

NUMBER SERIAL C189 D4

Inverter Gen5 — Chassis2 Hardware Release | 1

# DRC — IOBoard

No DRC errors (warnings suppressed).

Inverter Gen5 — Chassis2 Hardware Release | 1

# CAPACITOR TEMP SENSE WIRING HARNESS

## HW-C2-WH-TSBCM-A · wiring harness — schematic

### All harnesses shall be constructed using #22 AWG stranded

HW-C2-WH-TSBCM PLACEHOLDER FOR BOM Z1 SXH-⁰⁰¹T-P0.6 PLACEHOLDER FOR BOM Z2 SXH-⁰⁰¹T-P0.6

conductor, 1kV rated, PVC insulated
wire (or cross-linked
polyolefin where higher temperature
rating is required).
Conductors shall be color-coded per
MIL-STD-681D (see chart
below). Terminations shall be
crimped using approved tooling
with pull-test verification per
IPC/WHMA-A-620, Chapter 19.
Harnesses shall be bundled with
lacing cord or expandable
braided sleeving; tie-wraps are
acceptable only in non-vibration
environments per drawing callout.
All harnesses require 100%
continuity and 500V DC hipot testing
prior to release. RoHS
compliance required unless otherwise
specified.

CONNECTOR HOUSING BLK

AND ADHERED WITH THERMALLY CONDUCTIVE MATERIAL. RED

NOTE: THERMISTOR SHOULD BE SECURELY PLACED INSIDE DC LINK CAPACITOR MODULE BETWEEN CAPACITORS

COLOR CODE CHART (MIL-STD-681D)

Prepared by Thomas Liao
Corzine Lab, University of California, Santa Cruz
Sheet: /
File: CapacitorTempSenseHarness.kicad_sch
Title: InverterGen5 - Capacitor Temp Sense Wiring Harness
KiCad E.D.A. 10.0.3

Inverter Gen5 — Chassis2 Hardware Release | 1

# CURRENT SENSOR WIRING HARNESS

## HW-C2-WH-CS-A · wiring harness — schematic

# HW-C2-WH-CS PLACEHOLDER FOR BOM PIN5 08⁻⁵⁰-⁰¹¹³

0022011042 | Wiring Harness Note

D Date: 2026-07-16; Size: USLetter; Rev: A; PLACEHOLDER FOR BOM PIN6 08-⁵⁰-⁰¹¹³; PLACEHOLDER FOR BOM PIN8 08-⁵⁰-⁰¹¹³ PLACEHOLDER FOR BOM PIN7 08-⁵⁰-⁰¹¹³; LA37S600S05KMCS1; PLACEHOLDER FOR BOM PIN4 08-⁵⁰-⁰¹¹³ PLACEHOLDER FOR BOM PIN3 08-⁵⁰-⁰¹¹³ PLACEHOLDER FOR BOM PIN1 08-⁵⁰-⁰¹¹³; PLACEHOLDER FOR BOM PIN2 08-⁵⁰-⁰¹¹³; Cond# Color; Abbr; Black; BLK; Brown; BRN; Red; RED; Orange; ORG; Yellow; YEL; Green; GRN; Blue; BLU; Violet; VIO; Gray; GRY; White; WHT; TWISTED PAIR; <- SENSOR SIDE BLK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

All harnesses shall be constructed
using #22 AWG stranded
conductor, 1kV rated, PVC insulated
wire (or cross-linked
polyolefin where higher temperature
rating is required).
Conductors shall be color-coded per
MIL-STD-681D (see chart
below). Terminations shall be
crimped using approved tooling
with pull-test verification per
IPC/WHMA-A-620, Chapter 19.
Harnesses shall be bundled with
lacing cord or expandable
braided sleeving; tie-wraps are
acceptable only in non-vibration
environments per drawing callout.
All harnesses require 100%
continuity and 500V DC hipot testing
prior to release. RoHS
compliance required unless otherwise
specified.

BOARD SIDE, CONNECT TO CURRENT SENSE ON CONTROL BOARD ->

ASSEMBLY IS GENERIC TO PHASE U/V/W/DC LINK

FOR SIGNAL INTEGRITY, IT IS IMPORTANT THAT ALL CURRENT SENSE CONDUCTORS ARE TIGHTLY AND EVENLY TWISTED TOGETHER

PLACEHOLDER FOR BOM

COLOR CODE CHART (MIL-STD-681D)

Prepared by Thomas Liao
Corzine Lab, University of California, Santa Cruz
Sheet: /
File: CurrentSenseHarness.kicad_sch
Title: InverterGen5 - Current Sensor Wiring Harness
KiCad E.D.A. 10.0.3

Inverter Gen5 — Chassis2 Hardware Release | 1

# GATE DRIVE WIRING HARNESS

## HW-C2-WH-GDVS-A · wiring harness — schematic

544959-E | PLACEHOLDER FOR BOM PIN15 464762-E PLACEHOLDER FOR BOM PIN13 464762-E PLACEHOLDER FOR BOM PIN14 464762-E PLACEHOLDER FOR BOM PIN3 464762-E PLACEHOLDER FOR BOM PIN4 464762-E | PLACEHOLDER FOR BOM PIN6 464762-E | PLACEHOLDER FOR BOM PIN8 464762-E | PLACEHOLDER FOR BOM PIN12 464762-E PLACEHOLDER FOR BOM PIN9 464762-E | PLACEHOLDER FOR BOM PIN11 464762-E PLACEHOLDER FOR BOM PIN10 464762-E PLACEHOLDER FOR BOM PIN7 464762-E

### Wiring Harness Note

VOLTAGE SENSE CONNECTOR
PLUGS INTO J15 ON CONTROL BOARD <- SPLICE AT J1

All harnesses shall be constructed
using #22 AWG stranded
conductor, 1kV rated, PVC insulated
wire (or cross-linked
polyolefin where higher temperature
rating is required).
Conductors shall be color-coded per
MIL-STD-681D (see chart
below). Terminations shall be
crimped using approved tooling
with pull-test verification per
IPC/WHMA-A-620, Chapter 19.

J15 ON FILTER BOARD

Harnesses shall be bundled with
lacing cord or expandable
braided sleeving; tie-wraps are
acceptable only in non-vibration
environments per drawing callout.
All harnesses require 100%
continuity and 500V DC hipot testing
prior to release. RoHS
compliance required unless otherwise
specified.

SPLICE AT IGBT CRIMP ->

COLOR CODE CHART (MIL-STD-681D)

HW-C2-WH-GVDS
Prepared by Thomas Liao
Corzine Lab, University of California, Santa Cruz
Sheet: /
File: GDVSHarness.kicad_sch
Title: InverterGen5 - Gate Drive Wiring Harness
KiCad E.D.A. 10.0.3

Inverter Gen5 — Chassis2 Hardware Release | 1

# IGBT TEMPERATURE WIRING HARNESS

## HW-C2-WH-TSIGBT-A · wiring harness — schematic

### Wiring Harness Note

### All harnesses shall be constructed

D Date: 2026-07-16; Size: USLetter; Rev: A; TH1 RTS103C1R2M6L201; 455-2266-ND PLACEHOLDER FOR BOM Z2 SXH-⁰⁰¹T-P0.6; PLACEHOLDER FOR BOM Z1 SXH-⁰⁰¹T-P0.6; Cond# Color; Abbr; Black; BLK; Brown; BRN; Red; RED; Orange; ORG; Yellow; YEL; Green; GRN; Blue; BLU; Violet; VIO; Gray; GRY; White; WHT; TWISTED; PAIR RED; NTC Thermistors 10K +-2%,M6 LUG,200MM WIRELGTH

using #22 AWG stranded
conductor, 1kV rated, PVC insulated
wire (or cross-linked
polyolefin where higher temperature
rating is required).
Conductors shall be color-coded per
MIL-STD-681D (see chart
below). Terminations shall be
crimped using approved tooling
with pull-test verification per
IPC/WHMA-A-620, Chapter 19.
Harnesses shall be bundled with
lacing cord or expandable
braided sleeving; tie-wraps are
acceptable only in non-vibration
environments per drawing callout.
All harnesses require 100%
continuity and 500V DC hipot testing
prior to release. RoHS
compliance required unless otherwise
specified.

CONNECTOR HOUSING BLK

COLOR CODE CHART (MIL-STD-681D)

HW-C2-WH-TSIGBT
Prepared by Thomas Liao
Corzine Lab, University of California, Santa Cruz
Sheet: /
File: TempSenseHarness.kicad_sch
Title: InverterGen5 - IGBT Temperature Wiring Harness
KiCad E.D.A. 10.0.3

Inverter Gen5 — Chassis2 Hardware Release | 1

# DESIGN DOCUMENTS

## project documentation — safety, security, manual, analyses

Inverter Gen5 — Chassis2 Hardware Release | 1

# THERMAL ANALYSIS — DC LINK MODULE STANDOFF HEAT PATH

## HW-C2-DOC-DC-LINK-THERMAL-ANAL-A · design document — rev A

# D E S I G N D O C U M E N T

# Thermal Analysis — DC Link Module Standoff Heat Path

Part | HW-C2-DOC-DC-LINK-THERMAL-ANAL-A · Rev A

## University of California, Santa Cruz — Corzine Lab

Traction Inverter | 1

# Contents

Traction Inverter | 2

# Thermal Analysis — DC Link Module Standoff Heat Path

Heat load at rated ripple was calculated to be 40W across all capacitors.

# 1. Methodology

# All calculations use one-dimensional steady-state thermal resistance:

# ΔT = Q × R_th

# where

# R_th = L / (k × A)

# Total system resistance is the sum of three series components:

# Standoff conduction — R_standoff = L / (k_standoff × A_standoff × n)

Contact resistance (both faces in series) — R_contact = (2 × ρ_contact) / (n × A_standoff)

# Aluminium spreading — R_spread ≈ (ln(r_cell / r_standoff) − 0.5) / (2π × k_Al × t_Al)

# Material properties

Material | Thermal conductivity k [W/(m·K)]
Aluminium (6063 / generic) | 200
Brass (C36000) | 120
Copper (C11000) | 400
Carbon steel | 50
18-8 Stainless steel | 16

# Contact resistivity values

Condition | Resistivity ρ_contact [m²·K/W]
Dry metal-to-metal | 1.0 × 10⁻⁴
With thermal paste / thin pad | 5.0 × 10⁻⁵

# Geometry constants

Heat-spreader plate: 3.18 mm (1/8 in) thick aluminium (corrected from 4 mm to match the fabricated plate,

# HW-C2-PLT-CHSP-A; all spreading-resistance values below use 3.18 mm) Standoff length: 55 mm (final design) Number of standoffs: 6 (final design) Standoff spacing: assumed ~100 mm centre-to-centre (spreading cell radius r_cell ≈ 50 mm)

1.
2.
3.

•

•
•
•
Traction Inverter | 3

# 2. Design Evolution

# 2.1 Initial concepts (for reference)

Configuration | k [W/m·K] | Area [mm²] | R_standoff [K/W] | ΔT_standoff [°C] | Total ΔT (paste) [°C]
8 mm hex brass, hollow M5 | 120 | 35.8 | 2.13 | 85.4 | 123
10 mm hex Al, hollow M5 | 200 | 67.0 | 0.684 | 27.4 | 53.9
16 mm round Al, hollow M8 | 200 | 150.8 | 0.304 | 12.2 | 29.9
16 mm round Al, solid | 200 | 201.1 | 0.228 | 9.1 | 25.8

All at 40 W, 6 standoffs, 55 mm long. Values rounded.

# 2.2 Selected design — 13 mm round aluminium spacers

Final part specification: - Outer diameter: 13.0 mm - Inner diameter (M6 clearance): 6.3 mm
(Note: M6 major diameter = 6.0 mm; 6.3 mm ID provides thread engagement or clearance depending on part type)
- Wall thickness: 3.35 mm - Length: 55 mm - Material: Aluminium - Thread: M6 × 1 (male-female or through-hole

# with bolt) - Quantity: 6

# Cross-sectional area:

# A = π × (r_outer² − r_inner²) = π × (6.5² − 3.15²) × 10⁻⁶ = 101.6 × 10⁻⁶ m²

# 3. Final Design Calculation

# 3.1 Standoff conduction resistance

# R_standoff = L / (k_Al × A × n) = 0.055 / (200 × 101.6 × 10⁻⁶ × 6) = 0.451 K/W

# ΔT_standoff = 40 × 0.451 = 18.1 °C

# 3.2 Contact resistance (both faces)

# With thermal paste:

# R_contact = (2 × 5.0 × 10⁻⁵) / (6 × 101.6 × 10⁻⁶) = 0.164 K/W

# ΔT_contact = 40 × 0.164 = 6.6 °C

# Dry metal-to-metal:

# R_contact = (2 × 1.0 × 10⁻⁴) / (6 × 101.6 × 10⁻⁶) = 0.328 K/W

# ΔT_contact = 40 × 0.328 = 13.1 °C

# 3.3 Aluminium spreading resistance

# R_spread = (ln(50 / 6.5) − 0.5) / (2π × 200 × 0.00318) ≈ 0.385 K/W

# ΔT_spread = 40 × 0.385 = 15.4 °C

Traction Inverter | 4

(Spreading resistance is independent of standoff material; it depends only on plate conductivity, thickness, and cell

# geometry.)

# 3.4 Total temperature rise

Condition | ΔT_total
With thermal paste | 18.1 + 6.6 + 15.4 = 40.1 °C
Dry metal-to-metal | 18.1 + 13.1 + 15.4 = 46.6 °C

# 3.5 Absolute temperatures (heatsink base = 40 °C)

Condition | Aluminium plate temperature
With thermal paste | ~80 °C
Dry metal-to-metal | ~87 °C

450 V capacitor-only upgrade: The 450 V upgrade is a single part-number swap to 60× Nichicon UCS2W680MHD 68 µF / 450 V capacitors (4.08 mF total). These parts are 5 mm shorter than the 200 V UCS2D331MHD, so the standoff length is reduced by 5 mm (from 55 mm to 50 mm). The same 13 mm OD aluminium standoff thermal path applies, with marginally lower conduction resistance due to the shorter length.

# 4. Sensitivity & Margin

# 4.1 Effect of standoff material

# If stainless steel (18-8, k = 16 W/m·K) were used instead of aluminium:

# ΔT_standoff = 40 × 0.055 / (16 × 101.6 × 10⁻⁶ × 6) ≈ 226 °C

Total rise would exceed 245 °C. Stainless steel is not acceptable for this thermal path.

# 4.2 Effect of quantity

Standoff count | R_standoff [K/W] | ΔT_standoff [°C] | Total ΔT (paste) [°C]
4 | 0.677 | 27.1 | 52.3
6 (selected) | 0.451 | 18.1 | 40
8 | 0.338 | 13.5 | 33.9

Six standoffs provides adequate margin; eight would be better but is not required at 40 W.

# 4.3 Effect of length

Length [mm] | ΔT_standoff [°C] | Total ΔT (paste) [°C]
30 | 9.9 | 32
55 (selected) | 18.1 | 40
65 | 21.4 | 43
Traction Inverter | 5

# 5. Recommendations

Use aluminium standoffs/spacers only. Do not substitute stainless or carbon steel.
Apply thermal paste (or a thin graphite / indium thermal pad) at both the plate-to-standoff and standoff-to-heatsink interfaces. This saves ~6.5 °C and improves long-term thermal stability.
Ensure adequate clamping force on the M6 bolts to minimize contact resistance. Target ~5–10 N·m on steel bolts into aluminium.
Verify standoff placement is reasonably distributed across the plate. Uneven distribution will increase local spreading resistance and hot-spot temperatures.
If power increases above ~60 W, consider upgrading to 8 standoffs or thicker-wall spacers (e.g., 16 mm OD / 6 mm ID).

# 6. Assumptions & Limitations

One-dimensional conduction assumed; actual 3D spreading may vary ±20 %.
Contact resistivity values are typical estimates; actual values depend on surface finish, flatness, and clamping pressure.
Heat generation is assumed uniform across the aluminium plate. Localised hot spots will increase peak temperatures.
Radiation and natural convection from the plate are neglected; in reality they provide additional heat rejection, so actual plate temperature may be slightly lower.
Ambient / heatsink base temperature is assumed constant at 40 °C; if the heatsink warms up under load, the absolute plate temperature rises proportionally.

Prepared for DC link module thermal design review.

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
Traction Inverter | 6

Inverter Gen5 — Chassis2 Hardware Release | 1

# HAZARD ANALYSIS & RISK ASSESSMENT

## HW-C2-DOC-HARA-A · design document — rev A

# H A Z A R D A N A L Y S I S & R I S K A S S E S S M E N T

# Traction Inverter

MCUs | STM32H723ZG + STM32G474RCTx

# Operating Temp −40 °C to +85 °C

Version | 4.1
Prepared by | Thomas Liao
Reviewed by | (not yet reviewed)
Date | July 13, 2026
Part | HW-C2-DOC-HARA-A · Rev A

## University of California, Santa Cruz — Corzine Lab

Traction Inverter | 1

# Contents

# 1. Introduction | 4

## 1.1 Compliance Statement | 4

## 1.2 Scope | 5

## 1.3 Reference Standards | 5

# 2. Item Definition | 6

## 2.1 System Boundaries | 6

## 2.2 Architecture Overview | 6

## 2.3 Mitigation Strategy | 9

## 2.4 Technical Parameters | 11

## 2.5 Gate Drivers (Non-ASIL) | 12

## 2.6 Onboard Power | 12

## 2.7 Future Considerations | 13

# 3. Operational Situations | 13

# 4. Hazard Identification (HAZID) | 14

# 5. Risk Assessment & ASIL Assignment | 16

## ASIL Assignment | 16

# 6. Safety Goals | 18

# 7. Functional Safety Requirements | 19

# 8. Current Design Coverage | 20

# 9. Gap Analysis | 21

## 9.1 Architecture Gaps | 21

## 9.2 Component Gaps | 22

## 9.2 Gap Summary | 22

# 10. Fault Injection Test Plan | 23

## 10.1 Test Philosophy | 23

## 10.2 Test Environment | 24

## 10.3 Component-Level Tests | 25

## 10.4 System-Level Tests | 43

## 10.5 Integration Tests | 53

## 10.6 Safety Goal Traceability | 60

## 10.7 Coverage Justification | 61

## 10.8 Pass/Fail Criteria | 63

## 10.9 Known Test Limitations | 64

## 10.10 Environmental and Stress Tests | 66

## 10.11 Recommended Test Execution Order | 71

# 11. Implementation Roadmap | 76

## 11.1 Phase 1: Safety-Critical Foundation (Immediate) | 76

## 11.2 Phase 2: Graceful Degradation (Short Term) | 76

## 11.3 Phase 3: Test Execution and Validation | 76

## 11.4 Coprocessor Integration Validation | 77

# References | 78

Traction Inverter | 2

## Document History | 78

Traction Inverter | 3

# 1. Introduction

# 1.1 Compliance Statement

# This Is Not an ISO 26262 Compliance Claim

This document applies ISO 26262:2018 methodology (Part 3: Concept Phase) to identify hazards, assess risk via Severity/Exposure/Controllability classification, and derive Safety Goals with ASIL

# ratings. The following must be understood clearly:

# ASIL ratings are targets derived from the HARA process. They represent the assessed risk

level of identified hazardous events, not a claim that the design has been verified or certified to meet those ASILs.

# The system described is not ISO 26262 compliant. Full compliance would require: complete

product development per Parts 4-6, hardware architectural metrics (SPFM ≥ 90% for ASIL B, ≥ 97% for ASIL D; LFM ≥ 60% for ASIL B, ≥ 80% for ASIL D), dependent failure analysis (DFA), software tool qualification, verification and validation testing (including fault injection), configuration management, change control, and independent safety assessment. None of these have been completed.
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

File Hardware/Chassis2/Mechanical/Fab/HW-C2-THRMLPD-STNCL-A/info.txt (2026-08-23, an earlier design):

PartName=Thermal Pad Cutting Stencil
Material=PLA
Qty=1
Finish=as printed
Process=3D Printing
Notes=Stencil/template for tracing and cutting the capacitor heatspreader thermal pad. Any rigid filament is fine.

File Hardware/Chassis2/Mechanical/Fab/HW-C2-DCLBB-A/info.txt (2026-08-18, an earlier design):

PartName=HW-C2-DCLBB-A
Material=Copper
Thickness_mm=4.75
Qty=2
Dimensions_in=12.357x0.551 in
Finish=Bending
UnitPrice=52.64
Process=Sheet Cutting
Notes=Imported from SendCutSend cart

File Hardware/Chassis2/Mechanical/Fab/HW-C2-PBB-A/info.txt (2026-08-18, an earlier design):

PartName=HW-C2-PBB-A
Material=Copper
Thickness_mm=4.75
Qty=3
Dimensions_in=0.591x3.38 in
Finish=Bending
UnitPrice=20.32
Process=Sheet Cutting
Notes=Imported from SendCutSend cart

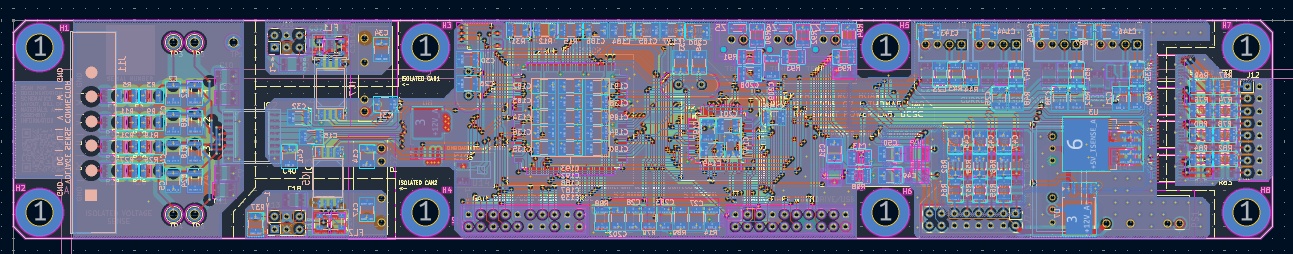
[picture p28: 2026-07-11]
Hardware/Chassis2/Boards/ControlBoard-Back.png

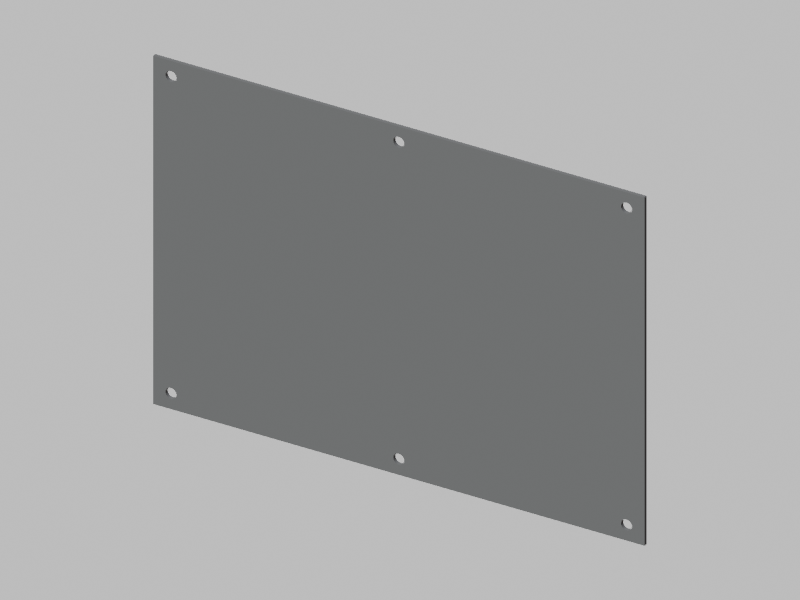
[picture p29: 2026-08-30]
Hardware/Chassis2/Mechanical/Fab/HW-C3-FR-FRNLID-A/info-back.png

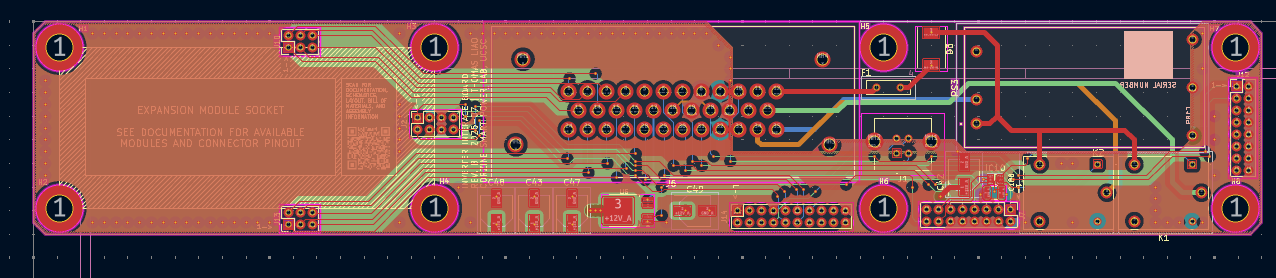
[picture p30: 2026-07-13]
Hardware/Chassis2/Boards/IOBoard-Front.png

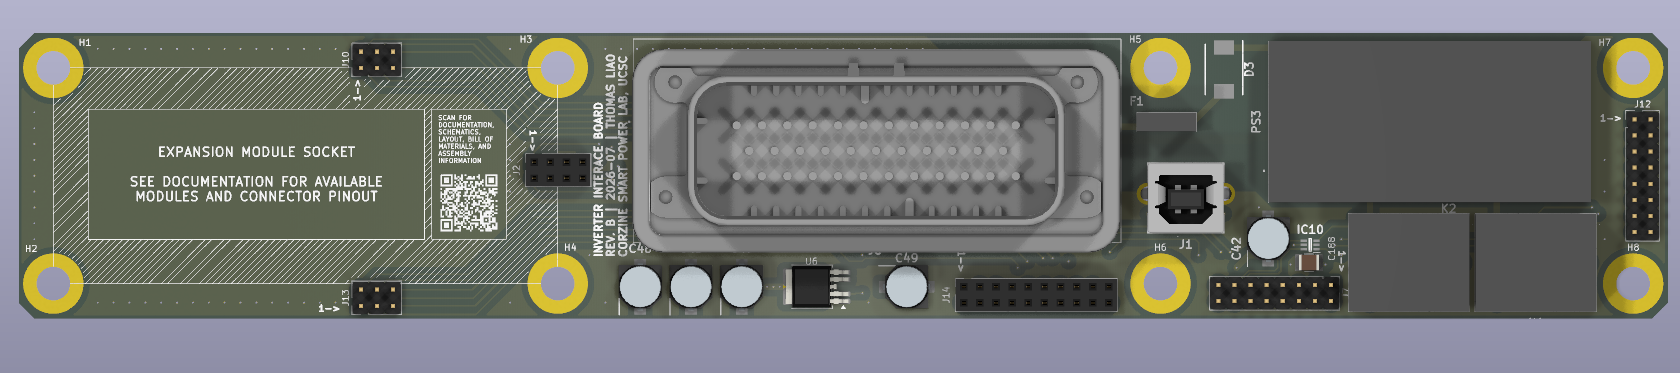
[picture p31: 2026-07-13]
Hardware/Chassis2/Boards/IOBoard.png

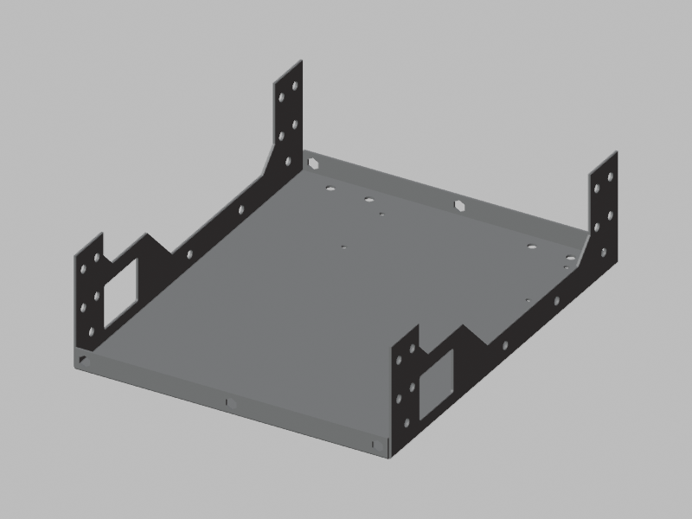
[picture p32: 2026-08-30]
Hardware/Chassis2/Mechanical/Fab/HW-C2-FR-BSP-A/info-back.png

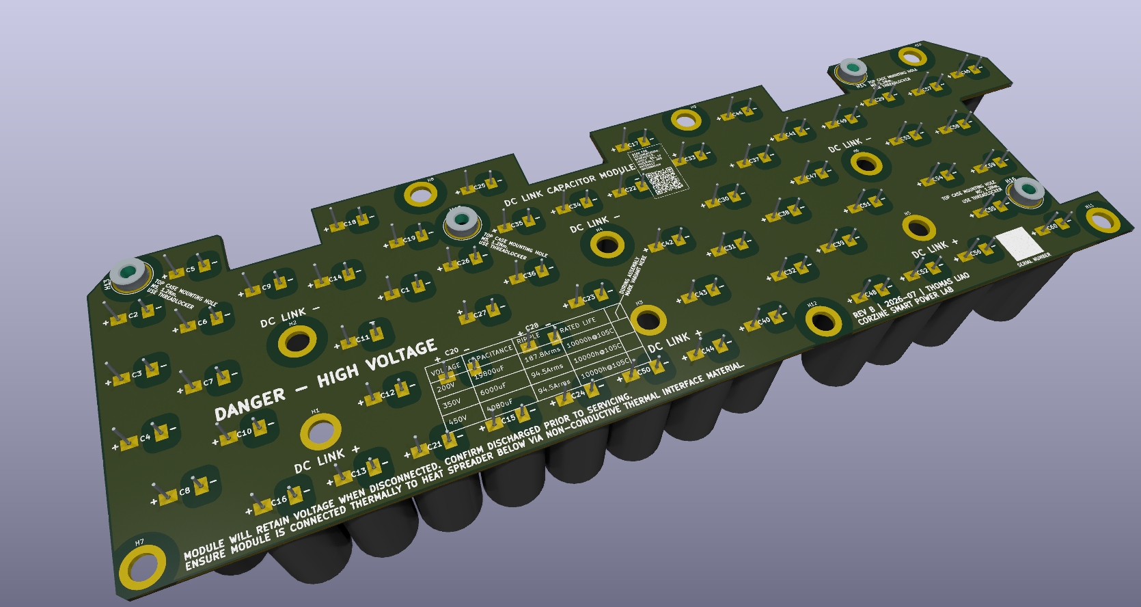
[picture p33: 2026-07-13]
Hardware/Chassis2/Boards/DCBusCapacitorBoard.png

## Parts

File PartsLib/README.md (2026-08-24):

# Parts Library

All files in this directory are **third-party or derived from third-party
sources**. They are **NOT** licensed under CERN-OHL-W.

This directory contains symbols, footprints, 3D models, and scripts sourced
from SnapEDA, UltraLibrarian, SamacSys, Mouser, DigiKey, manufacturers, and
other third parties. They remain under their respective original licenses and
terms of use.

These files are included as Available Components / External Material for
convenience only. If you use them outside this project, comply with the
original source's terms.

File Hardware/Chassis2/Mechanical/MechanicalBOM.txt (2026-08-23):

Qty,Vendor,PN,Description
1,Mouser,951-GP1500-080-02,Thermal gap pad
1,McMaster,1821A55,Dielectric grease
8,McMaster,90128A232,
5,McMaster,90225A102,
18,McMaster,91292A134,
1,McMaster,91458A112,Loctite 242 threadlocker 0.34 oz
6,McMaster,91502A180,
6,McMaster,91502A183,
6,McMaster,94669A190,
6,McMaster,94669A196,
12,McMaster,94669A199,
25,McMaster,98044A224,
3,Mouser,CM600DY-24T,IGBT module (CM600DY-13T recommended for 200-450 V; 24T also compatible)
8,McMaster,6926K352,6926K352_Tin-Plated Copper Compression Lug
5,McMaster,6926K56,6926K56_Tin-Plated Copper Compression Lug
1,McMaster,7381K23,7381K23_Threaded Plug for Enclosures
4,McMaster,91292A108,91292A108_18-8 Stainless Steel Socket Head Screw
4,McMaster,94180A351,94180A351_Brass Tapered Heat-Set Inserts for Plastic
12,McMaster,96738A257,96738A257_18-8 Stainless Steel Vibration-Resistant Sealing Socket Head Screw
4,McMaster,92125A228,92125A228_18-8 Stainless Steel Hex-Drive Flat Head Screw

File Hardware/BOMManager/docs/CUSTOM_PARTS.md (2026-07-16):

# Custom Parts (McMaster-Carr and SendCutSend)

## McMaster-Carr Parts

McMaster-Carr has an approved-customer Product Information API (see
`API_KEYS.md`). If you configure the certificate-based credentials, the tool
uses the official API; otherwise it falls back to cached or manually set
prices.

### The mechanical list

`Hardware/<Chassis>/Mechanical/MechanicalBOM.txt` is owned by the tool — add
and change rows from the shell instead of editing by hand:

```text
bom> mech                                   # list with prices
bom> mech add McMaster 94669A199 12 M3x10 SHCS
bom> mech set 94669A199 20
bom> mech rm 94669A199
```

The file stays a plain CSV (`Qty,Vendor,PN,Description`), sorted and
deduplicated on every change. Any vendor string works (`McMaster`, `Digikey`,
`Mitsubishi`, ...). Set prices with `price <pn> <usd>`, and if the part comes
in a box, `pack <pn> 25 <box price>` — ordering then counts packs, not pieces.

## SendCutSend Fabricated Parts

Bus bars, plates, brackets, and other laser/waterjet-cut parts live one folder
per part under `Hardware/<Chassis>/Mechanical/Fab/<PartName>/`. Scaffold a new
one from the shell:

```text
bom> new fab DC Link Bus Bar
```

which creates:

```text
Hardware/<Chassis>/Mechanical/Fab/HW-C2-DCLBB-A/
├── info.txt        # specs and price (template)
└── README.md       # what goes here
```

Drop in `<folder>.step` (required) and `info.png` (optional, embedded in the
price report).

### `info.txt` fields

```ini
PartName=DC Link Bus Bar
Material=Copper
Thickness_mm=4.75
Qty=2
Dimensions_in=12.357x0.551 in
Finish=Bending
UnitPrice=50.71
Process=Sheet Cutting
Notes=Tin plate ends after forming
```

| Field | Description |
|---|---|
| PartName | Human-readable name. Words like "bus bar", "plate", "bracket" drive category detection. |
| Material | e.g., `Copper`, `5052 aluminum` |
| Thickness_mm | Sheet thickness in mm |
| Qty | Quantity per chassis |
| Dimensions_in or Dimensions_mm | Part dimensions |
| Finish | e.g., `as cut`, `Bending`, `tinned`, `anodized` |
| UnitPrice | USD per part |
| Process | e.g., `Sheet Cutting` |
| Notes | Design notes, tolerances, etc. |
| Rev | Managed by the tool (`rev bump`) — do not edit by hand. |

Each part gets an internal part number such as `HW-C2-BB-DCLBB-A`
(see `PART_NUMBERING.md`).

### Importing from a SendCutSend cart

After building a cart on SendCutSend, copy the page text and paste it:

```text
bom> import sendcutsend            # paste, then Ctrl+D
bom> import sendcutsend cart.txt   # or from a file
bom> import sendcutsend cart.txt --dry-run
```

The importer matches cart filenames to existing folders regardless of token
order (`C2_HW_BSP_A.step` matches `HW-C2-BSP-A`), creates missing folders, and
writes/updates each `info.txt` — including the quoted price.

### Revisions

`rev bump DCLBB --note "..."` bumps the revision and writes `Rev=` into
`info.txt`. Folders and STEP files are never renamed, so vendor re-uploads and
CAD links keep working.

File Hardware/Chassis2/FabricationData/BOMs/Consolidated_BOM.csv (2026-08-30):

Quantity | Order Qty | Pack Size | Leftover | Internal P/N | Description | Customer Part No. | Manufacturer Part No. | Vendor | Vendor P/N
6 | 6 |  |  | HW-C2-3DP-DC-LINK-MODULE-HOLDER-SP-A | DC Link Module Holder Spacer - Printed |  | DC Link Module Holder Spacer - Printed | sendcutsend | DC Link Module Holder Spacer - Printed
3 | 3 |  |  | HW-C2-3DP-DCLSPCR-PRINTED-A | HW-C2-DCLSPCR-PRINTED-B |  | HW-C2-DCLSPCR-PRINTED-B | sendcutsend | HW-C2-DCLSPCR-PRINTED-B
1 | 1 |  |  | HW-C2-3DP-SHELL-PRINTED-A | HW-C2-SHELL-PRINTED-A |  | HW-C2-SHELL-PRINTED-A | sendcutsend | HW-C2-SHELL-PRINTED-A
2 | 2 |  |  | HW-C2-BB-DCLBB-A | HW-C2-DCLBB-A |  | HW-C2-DCLBB-A | sendcutsend | HW-C2-DCLBB-A
3 | 3 |  |  | HW-C2-BB-PBB-A | HW-C2-PBB-A |  | HW-C2-PBB-A | sendcutsend | HW-C2-PBB-A
70 | 70 |  |  | HW-C2-CAP-100N-A | 100nF 100V | CBPN-JMGYO-100nF | 100nF | mouser | 80-C1210C104K1RAC
21 | 21 |  |  | HW-C2-CAP-10N-A | 10nF 500V | CBPN-FZHK8-10nF | 10nF | mouser | 187-CL32B103KGFNNNE
37 | 37 |  |  | HW-C2-CAP-10U-A | 10uF 25V | CBPN-Z2OBH-10uF | 10uF | mouser | 187-CL32A106KAULNNE
8 | 8 |  |  | HW-C2-CAP-1U-A | 1uf 50V | CBPN-6J4DK-1uf | 1uF | mouser | 187-CL32B105KBHNNNE
2 | 2 |  |  | HW-C2-CAP-2U2-A | 2.2uf 1210 100v | CBPN-X4VU0-22uf | 2.2uF | mouser | 80-C1210C225J1RAUTO
6 | 6 |  |  | HW-C2-CAP-220P-A | 220pF 100V C0G 1210 |  | 220pF | mouser | 80-C1210C221J2G
4 | 4 |  |  | HW-C2-CAP-22P-A | 22pF 50V | CBPN-XGV7B-22pF | 22pF | mouser | 80-C1210C220J5G
2 | 2 |  |  | HW-C2-IC-8MHZ-A | 8mhz hc49-4h crystal | CBPN-QQUPE-8mhz | 8MHz | mouser | 710-830003156B
1 | 1 |  |  | HW-C2-IC-CY15B102Q-SXET-A | CY15B102Q-SXET |  | CY15B102Q-SXET | mouser | 727-CY15B102Q-SXET
4 | 4 |  |  | HW-C2-IC-ISO1042BDWVR-A | ISO1042BDWVR |  | ISO1042BDWVR | mouser | 595-ISO1042BDWVR
1 | 1 |  |  | HW-C2-IC-ISO1212DBQ-A | ISO1212DBQ |  | ISO1212DBQ | mouser | 595-ISO1212DBQ
1 | 1 |  |  | HW-C2-IC-MAX22530AWE-A | MAX22530AWE+ |  | MAX22530AWE+ | mouser | 700-MAX22530AWE+
6 | 6 |  |  | HW-C2-IC-NCV57100DWR2G-A | NCV57100DWR2G |  | NCV57100DWR2G | mouser | 863-NCV57100DWR2G
1 | 1 |  |  | HW-C2-IC-STM32G474RCT3-A | STM32G474RCT3 |  | STM32G474RCT3 | mouser | 511-STM32G474RCT3
1 | 1 |  |  | HW-C2-IC-STM32H723ZGT6-A | STM32H723ZGT6 |  | STM32H723ZGT6 | mouser | 511-STM32H723ZGT6
1 | 1 |  |  | HW-C2-CONN-SSW-110-01-F-D-A | SSW-110-01-F-D |  | SSW-110-01-F-D | mouser | 200-SSW11001FD
1 | 1 |  |  | HW-C2-CONN-TSW-110-21-L-D-LL-A | TSW-110-21-L-D-LL |  | TSW-110-21-L-D-LL | mouser | 200-TSW11021LDLL
1 | 1 |  |  | HW-C2-MECH-1821A55-A | 1821A55 |  | 1821A55 | mcmaster | 1821A55
8 | 8 |  |  | HW-C2-MECH-6926K352-A | 6926K352 |  | 6926K352 | mcmaster | 6926K352
5 | 5 |  |  | HW-C2-MECH-6926K56-A | 6926K56 |  | 6926K56 | mcmaster | 6926K56
1 | 1 |  |  | HW-C2-MECH-7381K23-A | 7381K23 |  | 7381K23 | mcmaster | 7381K23
8 | 1 | 100 | 92 | HW-C2-MECH-90128A232-A | 90128A232 |  | 90128A232 | mcmaster | 90128A232
5 | 1 | 50 | 45 | HW-C2-MECH-90225A102-A | 90225A102 |  | 90225A102 | mcmaster | 90225A102
4 | 4 |  |  | HW-C2-MECH-91292A108-A | 91292A108 |  | 91292A108 | mcmaster | 91292A108
18 | 1 | 50 | 32 | HW-C2-MECH-91292A134-A | 91292A134 |  | 91292A134 | mcmaster | 91292A134
1 | 1 |  |  | HW-C2-MECH-91458A112-A | 91458A112 |  | 91458A112 | mcmaster | 91458A112
6 | 1 | 25 | 19 | HW-C2-MECH-91502A180-A | 91502A180 |  | 91502A180 | mcmaster | 91502A180
6 | 1 | 10 | 4 | HW-C2-MECH-91502A183-A | 91502A183 |  | 91502A183 | mcmaster | 91502A183
4 | 4 |  |  | HW-C2-MECH-92125A228-A | 92125A228 |  | 92125A228 | mcmaster | 92125A228
4 | 4 |  |  | HW-C2-MECH-94180A351-A | 94180A351 |  | 94180A351 | mcmaster | 94180A351
6 | 6 |  |  | HW-C2-MECH-94669A190-A | 94669A190 |  | 94669A190 | mcmaster | 94669A190
6 | 6 |  |  | HW-C2-MECH-94669A196-A | 94669A196 |  | 94669A196 | mcmaster | 94669A196
12 | 12 |  |  | HW-C2-MECH-94669A199-A | 94669A199 |  | 94669A199 | mcmaster | 94669A199
12 | 12 |  |  | HW-C2-MECH-96738A257-A | 96738A257 |  | 96738A257 | mcmaster | 96738A257
25 | 1 | 25 | 0 | HW-C2-MECH-98044A224-A | 98044A224 |  | 98044A224 | mcmaster | 98044A224
8 | 8 |  |  | HW-C2-HW-0022011042-A | 0022011042 |  | 0022011042 | mouser
32 | 32 |  |  | HW-C2-HW-08-50-0113-A | 08-50-0113 |  | 08-50-0113 | mouser
4 | 4 |  |  | HW-C2-HW-22-04-1041-A | 22-04-1041 |  | 22-04-1041 | mouser | 538-22-04-1041
3 | 3 |  |  | HW-C2-HW-455-2266-ND-A | 455-2266-ND |  | 455-2266-ND | mouser | 306-XHP-2
25 | 25 |  |  | HW-C2-HW-464762-E-A | 464762-E |  | 464762-E | mouser | 305-464762
5 | 5 |  |  | HW-C2-HW-524265-E-A | 524265-E |  | 524265-E | mouser | 305-524265-E
5 | 5 |  |  | HW-C2-HW-544959-E-A | 544959-E |  | 544959-E | mouser
1 | 1 |  |  | HW-C2-HW-776231-1-A | 776231-1 |  | 776231-1 | mouser | 571-776231-1
1 | 1 |  |  | HW-C2-HW-951-GP1500-080-02-A | 951-GP1500-080-02 |  | 951-GP1500-080-02 | mouser | 951-GP1500-080-02
8 | 8 |  |  | HW-C2-HW-971150581-A | 971150581 |  | 971150581 | mouser | 710-971150581
8 | 8 |  |  | HW-C2-HW-971250581-A | 971250581 |  | 971250581 | mouser | 710-971250581
8 | 8 |  |  | HW-C2-HW-971350581-A | 971350581 |  | 971350581 | mouser | 710-971350581
8 | 8 |  |  | HW-C2-HW-9774030592R-A | 9774030592R |  | 9774030592R | mouser | 710-9774030592R
2 | 2 |  |  | HW-C2-HW-ACT45B-101-2P-TL003-A | ACT45B-101-2P-TL003 |  | ACT45B-101-2P-TL003 | mouser | 810-ACT45B1012PTL003
2 | 2 |  |  | HW-C2-HW-AWHSH105D00G-A | AWHSH105D00G |  | AWHSH105D00G | mouser | 523-AWHSH105D00G
3 | 3 |  |  | HW-C2-HW-B2B-XH-AM_LF__SN_-A | B2B-XH-AM_LF__SN_ |  | B2B-XH-AM_LF__SN_ | mouser | 306-B2B-XH-AMLFSNP
12 | 12 |  |  | HW-C2-HW-B58031U9254M062-A | B58031U9254M062 |  | B58031U9254M062 | mouser | 871-B58031U9254M062
12 | 12 |  |  | HW-C2-HW-BAT54WS-7-F-A | BAT54WS-7-F |  | BAT54WS-7-F | mouser | 621-BAT54WS-F
5 | 5 |  |  | HW-C2-HW-BTS462TATMA1-A | BTS462TATMA1 |  | BTS462TATMA1 | mouser | 726-BTS462TATMA1
3 | 3 |  |  | HW-C2-HW-CM600DY-24T-A | CM600DY-24T (CM600DY-13T recommended for Chassis Size 2 200-450 V; 24T also compatible) |  | CM600DY-24T | mouser | CM600DY-24T
1 | 1 |  |  | HW-C2-HW-DC-LINK-MODULE-HOLDER-A | DC Link Module Holder - 200V Class |  | DC Link Module Holder - 200V Class | sendcutsend | DC Link Module Holder - 200V Class
1 | 1 |  |  | HW-C2-HW-DRDNB21D-7-A | DRDNB21D-7 |  | DRDNB21D-7 | mouser | 621-DRDNB21D-7
1 | 1 |  |  | HW-C2-HW-EC7BW-110S12-A | EC7BW-110S12 |  | EC7BW-110S12 | mouser | 418-EC7BW-110S12
12 | 12 |  |  | HW-C2-HW-FDFNYD1-110-5-A | FDFNYD1-110(5) |  | FDFNYD1-110(5) | mouser | 161-FDFNYD1-1105
4 | 4 |  |  | HW-C2-HW-LA37S600S05KM-A | LA37S600S05KM |  | LA37S600S05KM | mouser | 838-LA37S600S05KM
1 | 1 |  |  | HW-C2-HW-LT3080IQ-PBF-A | LT3080IQ#PBF |  | LT3080IQ#PBF | mouser | 584-LT3080IQ#PBF
2 | 2 |  |  | HW-C2-HW-LTST-C230CKT-A | LTST-C230CKT |  | LTST-C230CKT | mouser | 859-LTST-C230CKT
2 | 2 |  |  | HW-C2-HW-LTST-C230GKT-A | LTST-C230GKT |  | LTST-C230GKT | mouser | 859-LTST-C230GKT
1 | 1 |  |  | HW-C2-HW-MF-RHT200_32-2-A | MF-RHT200_32-2 |  | MF-RHT200_32-2 | mouser | 652-MF-RHT200/32-2
6 | 6 |  |  | HW-C2-HW-MGJ2D121509MPC-R7-A | MGJ2D121509MPC-R7 |  | MGJ2D121509MPC-R7 | mouser | 580-MGJ2D121509MPCR7
6 | 6 |  |  | HW-C2-HW-MKP1848S61010JY5B-A | MKP1848S61010JY5B |  | MKP1848S61010JY5B | mouser | 75-MKP1848S61010JY5B
5 | 5 |  |  | HW-C2-HW-MM3Z3V0ST1G-A | MM3Z3V0ST1G |  | MM3Z3V0ST1G | mouser | 863-MM3Z3V0ST1G
1 | 1 |  |  | HW-C2-HW-NXFT15XH103FEAB021-A | NXFT15XH103FEAB021 |  | NXFT15XH103FEAB021 | mouser | 81-NXFT15XH103FEAB21
1 | 1 |  |  | HW-C2-HW-RD7-12S033R-A | RD7-12S033R |  | RD7-12S033R | mouser | 737-RD7-12S033R
3 | 3 |  |  | HW-C2-HW-RKE-1205S_H-A | RKE-1205S_H |  | RKE-1205S_H | mouser | 919-RKE-1205S/H
2 | 2 |  |  | HW-C2-HW-RTS103C1R2M6L201-A | RTS103C1R2M6L201 |  | RTS103C1R2M6L201 | mouser | 527-RTS103C1R2M6L201
2 | 2 |  |  | HW-C2-HW-S3N-A | S3N |  | S3N | mouser | 512-S3N
2 | 2 |  |  | HW-C2-HW-SSW-103-01-L-D-A | SSW-103-01-L-D |  | SSW-103-01-L-D | mouser | 200-SSW10301LD
1 | 1 |  |  | HW-C2-HW-SSW-104-01-L-D-A | SSW-104-01-L-D |  | SSW-104-01-L-D | mouser | 200-SSW10401LD
2 | 2 |  |  | HW-C2-HW-SSW-108-01-L-D-A | SSW-108-01-L-D |  | SSW-108-01-L-D | mouser | 200-SSW10801LD
1 | 1 |  |  | HW-C2-HW-SSW-110-01-F-D-A | SSW-110-01-F-D |  | SSW-110-01-F-D | mouser
1 | 1 |  |  | HW-C2-HW-STS41A-AWLB-R3-A | STS41A-AWLB-R3 |  | STS41A-AWLB-R3 | mouser | 403-STS41A-AWLB-R3
6 | 6 |  |  | HW-C2-HW-STTH112A-A | STTH112A |  | STTH112A | mouser | 511-STTH112A
6 | 6 |  |  | HW-C2-HW-SXH-001T-P0-6-A | SXH-001T-P0.6 |  | SXH-001T-P0.6 | mouser | 306-SXH-001T-P0.6
4 | 4 |  |  | HW-C2-HW-SZMMSZ4678T1G-A | SZMMSZ4678T1G |  | SZMMSZ4678T1G | mouser | 863-SZMMSZ4678T1G
21 | 21 |  |  | HW-C2-HW-TESTPOINT-TH-RED-A | Testpoint TH, RED | CBPN-L3UB8-TestPoint | TestPoint | mouser | 534-5000
1 | 1 |  |  | HW-C2-HW-THERMAL-PAD-CUTTING-STEN-A | Thermal Pad Cutting Stencil |  | Thermal Pad Cutting Stencil | sendcutsend | Thermal Pad Cutting Stencil
1 | 1 |  |  | HW-C2-HW-TPS389006ADJRTER-A | TPS389006ADJRTER |  | TPS389006ADJRTER | mouser | 595-TPS389006ADJRTER
2 | 2 |  |  | HW-C2-HW-TS40-66-50-R-260-SMT-TR-A | TS40-66-50-R-260-SMT-TR |  | TS40-66-50-R-260-SMT-TR | mouser | 179-TS406650R260S
2 | 2 |  |  | HW-C2-HW-TSW-103-18-G-D-A | TSW-103-18-G-D |  | TSW-103-18-G-D | mouser | 200-TSW10318GD
2 | 2 |  |  | HW-C2-HW-TSW-108-18-F-D-A | TSW-108-18-F-D |  | TSW-108-18-F-D | mouser | 200-TSW10818FD
1 | 1 |  |  | HW-C2-HW-TSW-110-18-T-D-A | TSW-110-18-T-D |  | TSW-110-18-T-D | mouser | 200-TSW11018TD
13 | 13 |  |  | HW-C2-HW-UCM1H101MCL1GS-A | UCM1H101MCL1GS |  | UCM1H101MCL1GS | mouser | 647-UCM1H101MCL1GS
60 | 60 |  |  | HW-C2-HW-UCS2D331MHD-A | UCS2D331MHD |  | UCS2D331MHD | mouser | 647-UCS2D331MHD
1 | 1 |  |  | HW-C2-HW-UJ2-B-HR-G-V-A | UJ2-B-HR-G-V |  | UJ2-B-HR-G-V | mouser | 179-UJ2-B-HR-G-V
18 | 18 |  |  | HW-C2-HW-VY1222M47Y5UQ6TV0-A | VY1222M47Y5UQ6TV0 |  | VY1222M47Y5UQ6TV0 | mouser | 72-VY1222M47Y5UQ6TV0
1 | 1 |  |  | HW-C2-PCB-CTRL-A | ControlBoard |  | ControlBoard | pcb | ControlBoard
1 | 1 |  |  | HW-C2-PCB-DCBUSCAP-A | DCBusCapacitorBoard |  | DCBusCapacitorBoard | pcb | DCBusCapacitorBoard
1 | 1 |  |  | HW-C2-PCB-DCFLT-A | DCBusFilter |  | DCBusFilter | pcb | DCBusFilter
1 | 1 |  |  | HW-C2-PCB-GD-A | GateDriver |  | GateDriver | pcb | GateDriver
1 | 1 |  |  | HW-C2-PCB-IO-A | IOBoard |  | IOBoard | pcb | IOBoard
1 | 1 |  |  | HW-C2-PLT-BSP-A | HW-C2-BSP-A |  | HW-C2-BSP-A | sendcutsend | HW-C2-BSP-A
1 | 1 |  |  | HW-C2-PLT-CHSP-A | HW-C2-CHSP-B |  | HW-C2-CHSP-B | sendcutsend | HW-C2-CHSP-B
27 | 27 |  |  | HW-C2-RES-10K-A | 10k 1210 | CBPN-B3D5Z-10k | 10k | mouser | 603-AC1210JR-0710KL
4 | 4 |  |  | HW-C2-RES-120-A | 120 1210 | CBPN-K6UIE-120 | 120 | mouser | 603-AC1210FR-07120RL
17 | 17 |  |  | HW-C2-RES-1K-A | 1k 1210 | CBPN-F0NOB-1k | 1k | mouser | 603-RC1210FR-071KL
12 | 12 |  |  | HW-C2-RES-2R7-A | 2.7 ohm 1210 | CBPN-VEDNZ-27 | 2.7 | mouser | 667-ERJ-14BQF2R7U
16 | 16 |  |  | HW-C2-RES-20K-A | 20k 1210 resistor | CBPN-ZYB6M-20k | 20k | mouser | 667-ERJ-P14F2002U
1 | 1 |  |  | HW-C2-RES-220-A | 220 1210 | CBPN-SZ7LV-220 | 220 | mouser | 603-RC1210FR-07220RL
3 | 3 |  |  | HW-C2-RES-3K-A | 3k 1210 1% |  | 3k | mouser | 603-RC1210FR-073KL
3 | 3 |  |  | HW-C2-RES-4K7-A | 4.7k 1210 | CBPN-5Z102-47k | 4.7k | mouser | 71-CRCW12104K70FKEAH
1 | 1 |  |  | HW-C2-RES-499K-A | 499kohm 1210 resistor | CBPN-IPSO6-499k | 499k | mouser | 667-ERJ-P14F4993U
2 | 2 |  |  | HW-C2-RES-560-A | 560ohm 1210 resistor | CBPN-HMOLG-560 | 560 | mouser | 667-ERJ-P14F5600U
16 | 16 |  |  | HW-C2-RES-250K-A | Thick Film Resistors - SMD 1/2watt 249Kohms 1% | CBPN-MZWIW-250k | 250k | mouser | 71-CRCW1210-249K-E3
1 | 1 |  |  | HW-C2-WH-TSBCM-A | CapacitorTempSenseHarness |  | CapacitorTempSenseHarness | assembly
4 | 4 |  |  | HW-C2-WH-CS-A | CurrentSenseHarness |  | CurrentSenseHarness | assembly
1 | 1 |  |  | HW-C2-WH-GDVS-A | GDVSHarness |  | GDVSHarness | assembly
2 | 2 |  |  | HW-C2-WH-TSIGBT-A | TempSenseHarness |  | TempSenseHarness | assembly

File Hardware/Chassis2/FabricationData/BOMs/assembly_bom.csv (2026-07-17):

Quantity | Internal P/N | Description | Customer Part No. | Manufacturer Part No. | Vendor | Vendor P/N
1 | HW-C2-WH-TSBCM-A | CapacitorTempSenseHarness |  | CapacitorTempSenseHarness | assembly
4 | HW-C2-WH-CS-A | CurrentSenseHarness |  | CurrentSenseHarness | assembly
1 | HW-C2-WH-GDVS-A | GDVSHarness |  | GDVSHarness | assembly
2 | HW-C2-WH-TSIGBT-A | TempSenseHarness |  | TempSenseHarness | assembly

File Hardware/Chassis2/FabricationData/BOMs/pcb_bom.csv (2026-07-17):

Quantity | Internal P/N | Description | Customer Part No. | Manufacturer Part No. | Vendor | Vendor P/N
1 | HW-C2-PCB-CTRL-A | ControlBoard |  | ControlBoard | pcb | ControlBoard
1 | HW-C2-PCB-DCBUSCAP-A | DCBusCapacitorBoard |  | DCBusCapacitorBoard | pcb | DCBusCapacitorBoard
1 | HW-C2-PCB-DCFLT-A | DCBusFilter |  | DCBusFilter | pcb | DCBusFilter
1 | HW-C2-PCB-GD-A | GateDriver |  | GateDriver | pcb | GateDriver
1 | HW-C2-PCB-IO-A | IOBoard |  | IOBoard | pcb | IOBoard

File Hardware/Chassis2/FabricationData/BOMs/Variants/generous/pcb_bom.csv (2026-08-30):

Quantity | Internal P/N | Description | Customer Part No. | Manufacturer Part No. | Vendor | Vendor P/N
6 | HW-C2-PCB-CTRL-A | ControlBoard |  | ControlBoard | pcb | ControlBoard
6 | HW-C2-PCB-DCBUSCAP-A | DCBusCapacitorBoard |  | DCBusCapacitorBoard | pcb | DCBusCapacitorBoard
6 | HW-C2-PCB-DCFLT-A | DCBusFilter |  | DCBusFilter | pcb | DCBusFilter
6 | HW-C2-PCB-GD-A | GateDriver |  | GateDriver | pcb | GateDriver
6 | HW-C2-PCB-IO-A | IOBoard |  | IOBoard | pcb | IOBoard

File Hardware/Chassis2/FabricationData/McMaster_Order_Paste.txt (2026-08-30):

1821A55,1
6926K352,8
6926K56,5
7381K23,1
90128A232,1
90225A102,1
91292A108,4
91292A134,1
91458A112,1
91502A180,1
91502A183,1
92125A228,4
94180A351,4
94669A190,6
94669A196,6
94669A199,12
96738A257,12
98044A224,1

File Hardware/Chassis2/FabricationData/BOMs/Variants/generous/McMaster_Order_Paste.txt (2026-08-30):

1821A55,6
6926K352,13
6926K56,10
7381K23,6
90128A232,1
90225A102,1
91292A108,9
91292A134,1
91458A112,6
91502A180,1
91502A183,2
92125A228,9
94180A351,9
94669A190,11
94669A196,11
94669A199,18
96738A257,18
98044A224,2

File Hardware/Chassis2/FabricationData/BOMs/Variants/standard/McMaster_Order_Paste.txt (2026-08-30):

1821A55,3
6926K352,10
6926K56,7
7381K23,3
90128A232,1
90225A102,1
91292A108,6
91292A134,1
91458A112,3
91502A180,1
91502A183,1
92125A228,6
94180A351,6
94669A190,8
94669A196,8
94669A199,15
96738A257,15
98044A224,2

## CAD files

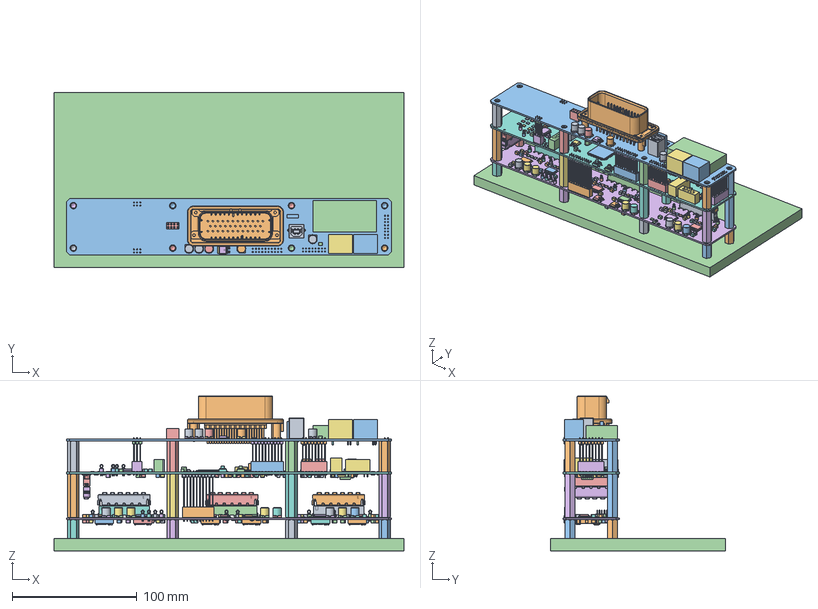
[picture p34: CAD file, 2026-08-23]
Hardware/Chassis0/Mechanical/InverterMechanical.FCStd
280.0 x 140.0 x 123.9 mm
TSW-110-21-S-D_body001
T-1S6-14-TSW-1-21-10-D001
R_1210_3225Metric
RKE_pin5(-Vout)
RKE_pin2(-Vin)
RKE_pin1(+Vin)
RKE_potting
RKE_pin7(+Vout)
RKE_case
B2B-XH-AM(LF)(SN)
C_1210_3225Metric
C_1210_3225Metric1600
R_1210_3225Metric1299
C_1210_3225Metric1602
RKE_pin5(-Vout)001
RKE_pin2(-Vin)001
RKE_pin1(+Vin)001
RKE_potting001
RKE_pin7(+Vout)001
RKE_case001
ï¿½ï¿½1
ï¿½ï¿½2
C_1210_3225Metric1604
C_1210_3225Metric1606
R_1210_3225Metric1301
C_1210_3225Metric1608
T1SSW-103-01-L-D
P2SSW-103-01-L-D
BODY-QFN
C_1210_3225Metric1610
B2B-XH-AM(LF)(SN)001
R_1210_3225Metric1303
T1SSW-108-01-L-D
P2SSW-108-01-L-D
C_1210_3225Metric1612
R_1210_3225Metric1305
TestPoint_Loop_D2_54mm_Drill1_5mm_Beaded_cp
SSOP-16_3.9x4.9mm_P0.635mm
T1SSW-108-01-L-D001
P2SSW-108-01-L-D001
R_1210_3225Metric1307
R_1210_3225Metric1309
LQFP-64_10x10mm_P0.5mm
TestPoint_Loop_D2_54mm_Drill1_5mm_Beaded_cp049
R_1210_3225Metric1311
C_1210_3225Metric1614
C_1210_3225Metric1616
T1SSW-103-01-L-D001
P2SSW-103-01-L-D001
TestPoint_Loop_D2_54mm_Drill1_5mm_Beaded_cp050
R_1210_3225Metric1313
ï¿½ï¿½001
ï¿½ï¿½002
R_1210_3225Metric1315
PinsArrayLR
R_1210_3225Metric1317
R_1210_3225Metric1319
LTST-C230GKT
LQFP-144_20x20mm_P0.5mm
C_1210_3225Metric1618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

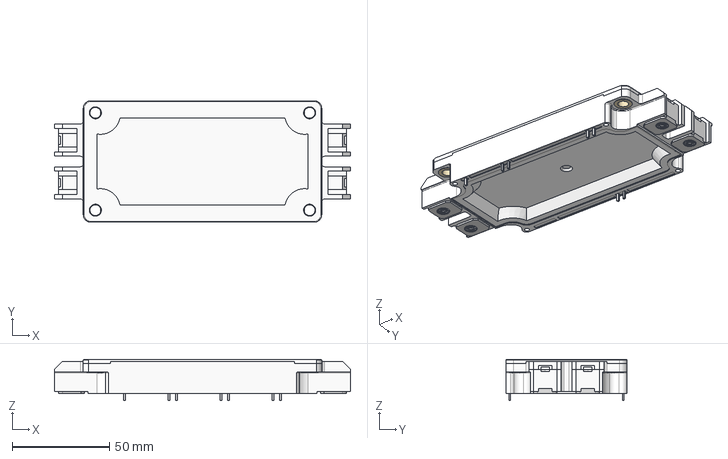
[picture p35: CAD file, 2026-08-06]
Hardware/Chassis1/Mechanical/FF900R12ME7WB11BPSA1.stp
152.0 x 62.0 x 21.3 mm

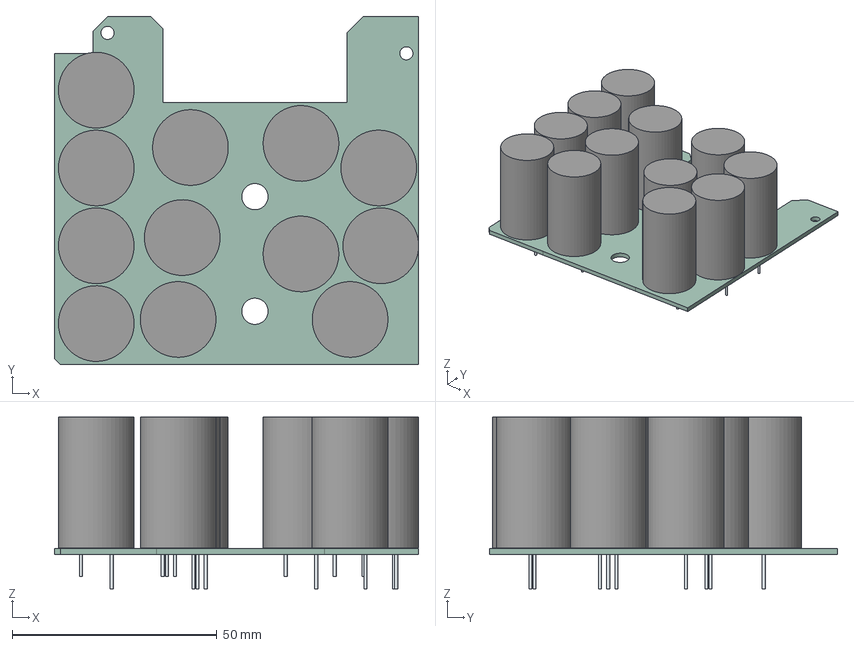
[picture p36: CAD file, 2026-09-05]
Hardware/Chassis2/Boards/DCBusCapacitorBoard/.step
89.0 x 85.0 x 42.0 mm
SimpleBody x 12
Pin1 x 12
Pin2 x 12
DCBusCapacitorBoard_PCB

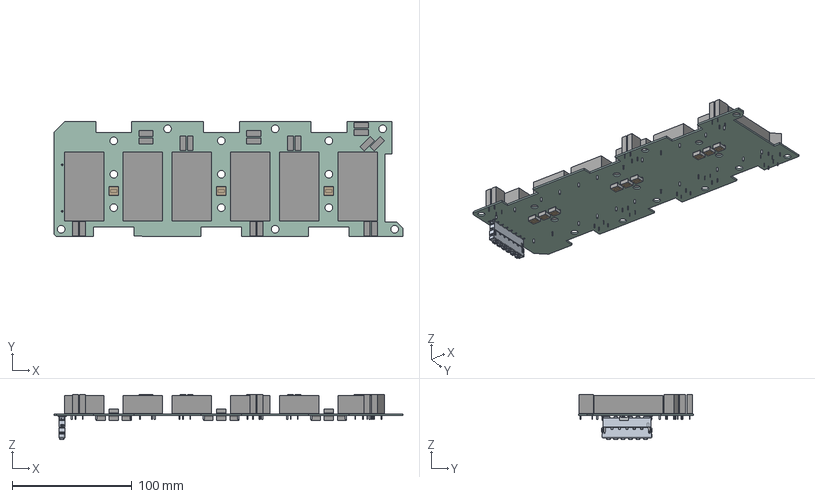
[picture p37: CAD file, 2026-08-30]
Hardware/Chassis2/Boards/DCBusFilter/DCBusFilter.step
292.0 x 96.1 x 37.8 mm
Leads x 42
CeraLink_LPJ_6097_Z03_Ind x 12
C-524264-E
C-544958-E
DCBusFilter_PCB

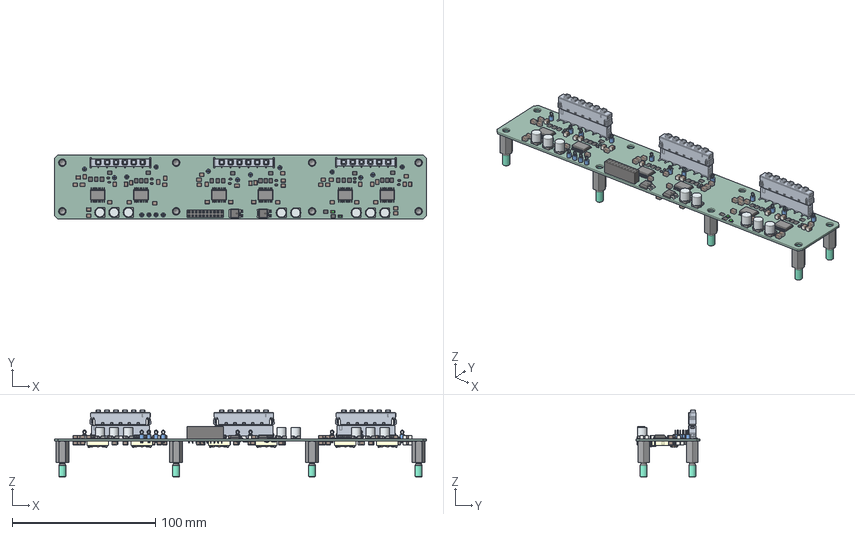
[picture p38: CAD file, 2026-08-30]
Hardware/Chassis2/Boards/GateDriver/GateDriver.step
260.0 x 45.0 x 46.5 mm
C_1210_3225Metric x 86
BODY-SOIC x 6
LEAD-DWE0016A x 96
R_1210_3225Metric x 32
Base x 8
Pin1Fillet x 8
Pin2Fillet x 8
TestPoint_Loop_D2_54mm_Drill1_5mm_Beaded_cp x 16
SOD323-PCB-001 x 12
SOD323-LP-001 x 12
PinSocket_2x10_P2.54mm_Vertical
LTST-C230GKT x 2
9bc26a55-9c39-11ed-93f0-dde97e994e83_part x 2
9bc26a56-9c39-11ed-93f0-dde97e994e83_part x 2
9bc26a57-9c39-11ed-93f0-dde97e994e83_part x 2
C-524264-E x 3
C-544958-E x 3
Uni-Directional x 6
FilletPinL x 2
FilletPinR x 2
mps_dcdc_mgj2d_mpc_a x 6
GateDriver_PCB

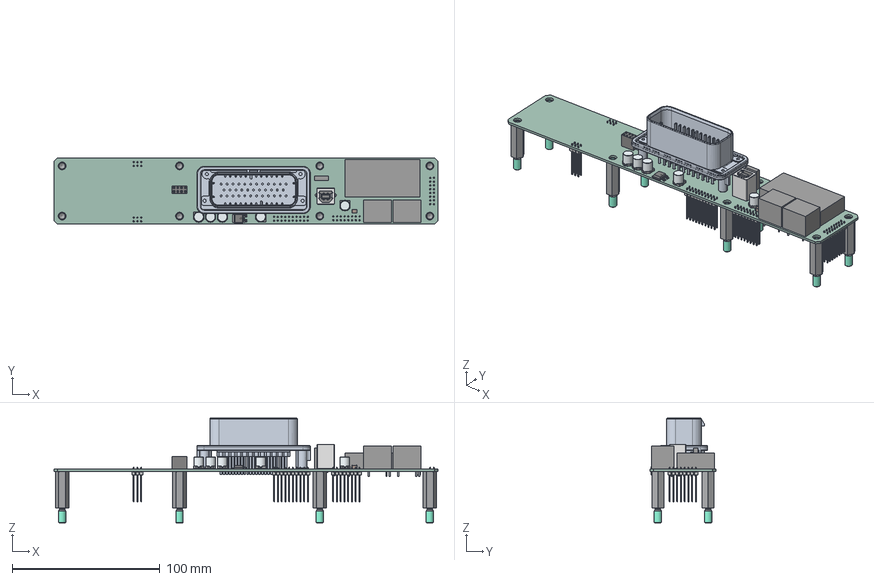
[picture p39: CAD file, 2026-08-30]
Hardware/Chassis2/Boards/IOBoard/IOBoard.step
260.0 x 45.0 x 70.8 mm
Leads x 10
Base x 5
Pin1Fillet x 5
Pin2Fillet x 5
TSW-108-18-F-D_body x 2
T-1S6-11-TSW-1-18-8-D x 2
C_1210_3225Metric x 2
9bc26a55-9c39-11ed-93f0-dde97e994e83_part
9bc26a56-9c39-11ed-93f0-dde97e994e83_part
9bc26a57-9c39-11ed-93f0-dde97e994e83_part
UJ2-B-HR-G-V
C-776231-1
TSW-103-18-G-D_body x 2
T-1S6-11-TSW-1-18-3-D x 2
TSW-110-18-T-D_body
T-1S6-11-TSW-1-18-10-D
PinSocket_2x04_P2.54mm_Vertical
IOBoard_PCB

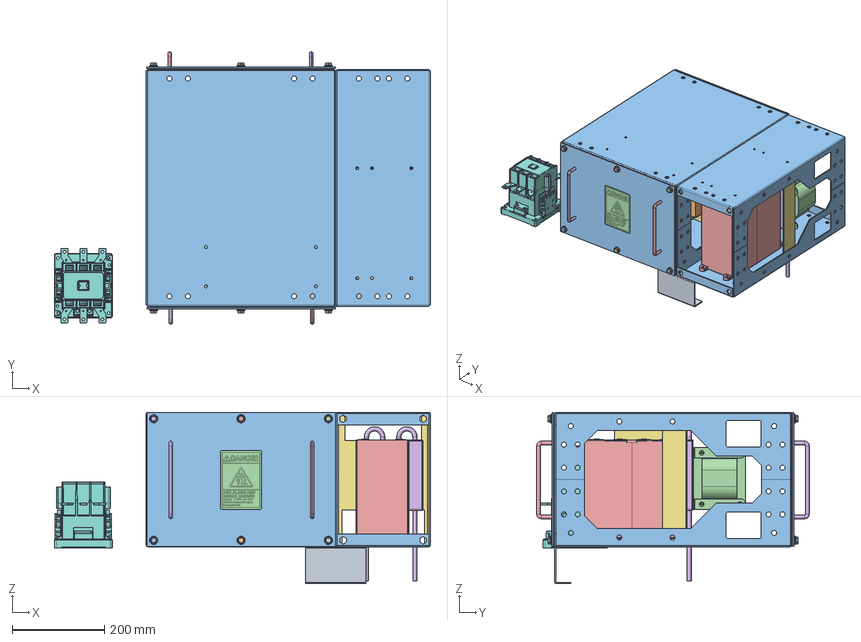
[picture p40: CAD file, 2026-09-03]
Hardware/Chassis2/Mechanical/DC-DC-Module.FCStd
813.5 x 589.6 x 371.0 mm
416201U00000G
416201U00000G001
HW-C2-FR-BSP-A x 2
90720A550_Heavy Duty Twist-Resistant Hex-Shaped Rivet Nuts002 x 2
90720A550_Heavy Duty Twist-Resistant Hex-Shaped Rivet Nuts003 x 2
90720A550_Heavy Duty Twist-Resistant Hex-Shaped Rivet Nuts004 x 2
90720A550_Heavy Duty Twist-Resistant Hex-Shaped Rivet Nuts005 x 2
90720A550_Heavy Duty Twist-Resistant Hex-Shaped Rivet Nuts006 x 2
90720A550_Heavy Duty Twist-Resistant Hex-Shaped Rivet Nuts007 x 2
90720A550_Heavy Duty Twist-Resistant Hex-Shaped Rivet Nuts008 x 2
90720A550_Heavy Duty Twist-Resistant Hex-Shaped Rivet Nuts009 x 2
90720A550_Heavy Duty Twist-Resistant Hex-Shaped Rivet Nuts010 x 2
90720A550_Heavy Duty Twist-Resistant Hex-Shaped Rivet Nuts011 x 2
90720A550_Heavy Duty Twist-Resistant Hex-Shaped Rivet Nuts012 x 2
90720A550_Heavy Duty Twist-Resistant Hex-Shaped Rivet Nuts013 x 2
HW-C3-FR-CSP-A x 4
90720A550_Heavy Duty Twist-Resistant Hex-Shaped Rivet Nuts x 4
90720A550_Heavy Duty Twist-Resistant Hex-Shaped Rivet Nuts001 x 4
HW-C3-FR-FRNLID-A x 2
5891T56_Accident Prevention Illustrated Labels x 2
1568A52_Threaded-Hole Round Pull Handle x 2
1568A52_Threaded-Hole Round Pull Handle001 x 2
91292A117_18-8 Stainless Steel Socket Head Screw x 8
91477A141_18-8 Stainless Steel Spring Lock Washer001 x 8
90166A718_18-8 Stainless Steel Flanged Hex Head Screw x 2
90166A718_18-8 Stainless Steel Flanged Hex Head Screw001 x 2
90166A718_18-8 Stainless Steel Flanged Hex Head Screw002 x 2
90166A718_18-8 Stainless Steel Flanged Hex Head Screw003 x 2
90166A718_18-8 Stainless Steel Flanged Hex Head Screw004 x 2
90166A718_18-8 Stainless Steel Flanged Hex Head Screw005 x 2
HW-C2-FR-CLPHLD-A
B25645A1328K003
195C100
195C101
HW-C2-FR-BSP-205-A x 2
195C102
B25645A1328K004
180-20-6C
HW-C2-FR-DCDC-205-HLDR-A
BEH-145
CN-FR-CONN-80mm

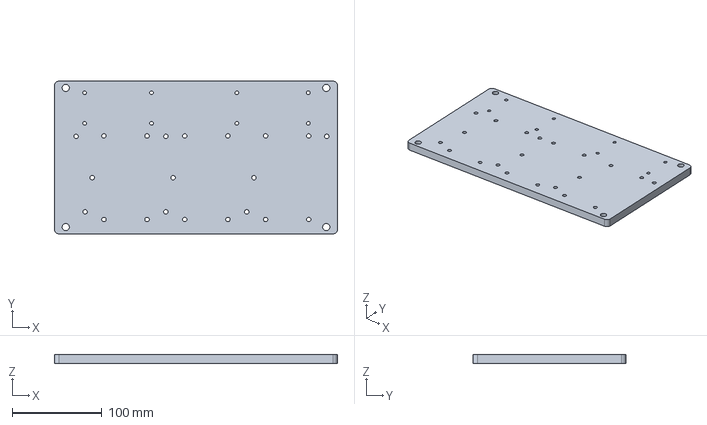
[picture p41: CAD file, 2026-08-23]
Hardware/Chassis2/Mechanical/Fab/HW-C2-BSP-A/HW-C2-BSP-A.step
315.0 x 170.0 x 10.0 mm

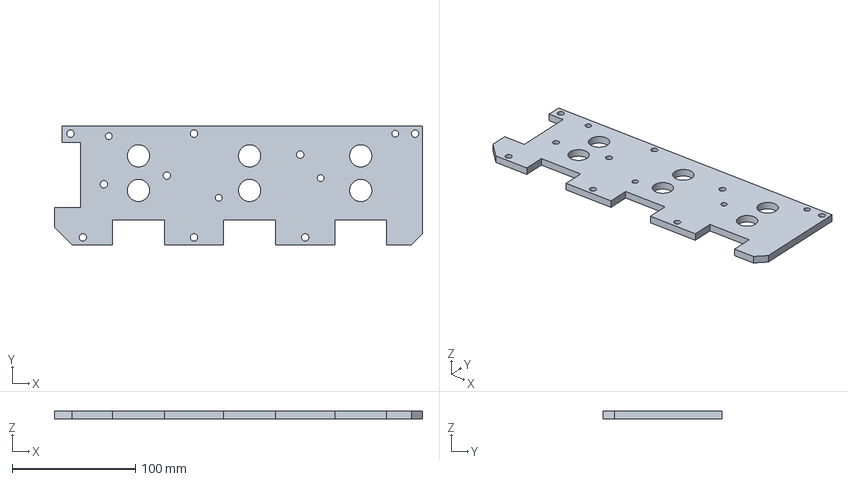
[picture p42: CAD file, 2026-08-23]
Hardware/Chassis2/Mechanical/Fab/HW-C2-CHSP-B/HW-C2-CHSP-B.step
298.0 x 96.0 x 6.35 mm

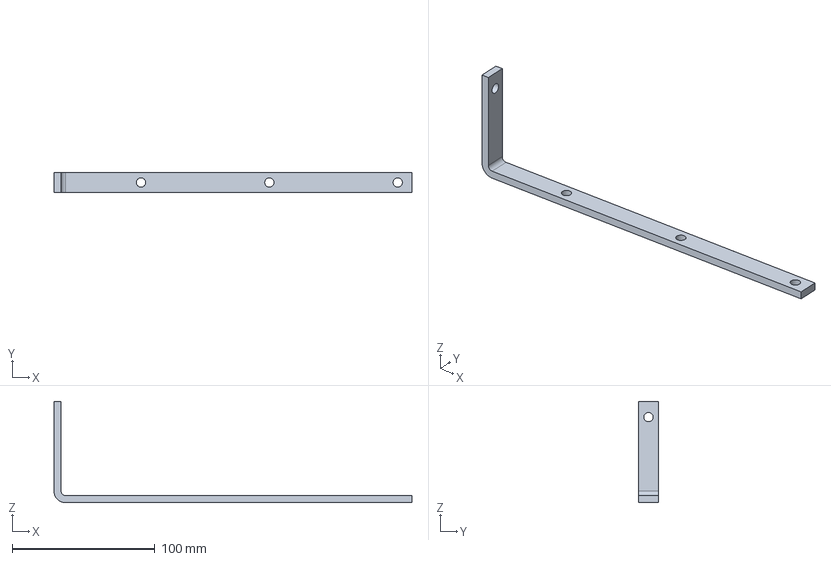
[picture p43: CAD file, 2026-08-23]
Hardware/Chassis2/Mechanical/Fab/HW-C2-DCLBB-A/HW-C2-DCLBB-A.step
251.0 x 14.0 x 71.0 mm

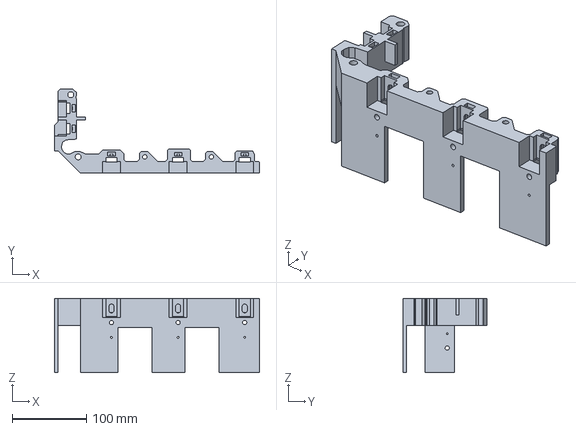
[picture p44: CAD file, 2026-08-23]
Hardware/Chassis2/Mechanical/Fab/HW-C2-DCLMH-200-PRINTED-B/HW-C2-DCLMH-200-PRINTED-B.step
277.0 x 114.0 x 100.0 mm

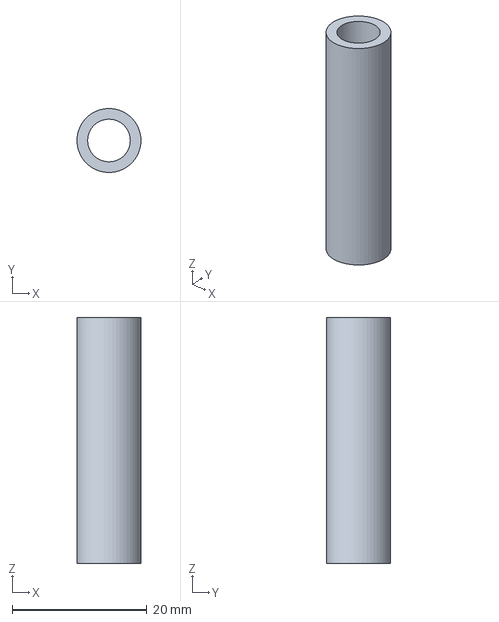
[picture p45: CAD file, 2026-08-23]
Hardware/Chassis2/Mechanical/Fab/HW-C2-DCLMH-200-SPCR-PRINTED-A/HW-C2-DCLMH-200-SPCR-PRINTED-A.step
9.49 x 9.50 x 36.5 mm

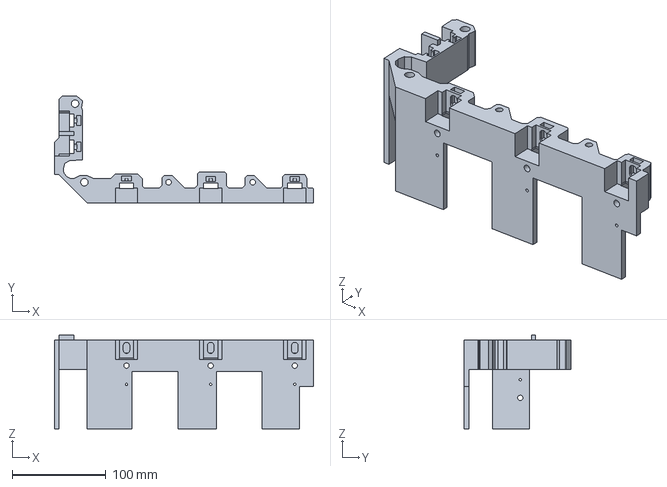
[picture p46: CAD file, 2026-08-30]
Hardware/Chassis2/Mechanical/Fab/HW-C2-DCLMH-450-PRINTED-A/HW-C2-DCLMH-450-PRINTED-A.step
277.0 x 114.0 x 100.0 mm

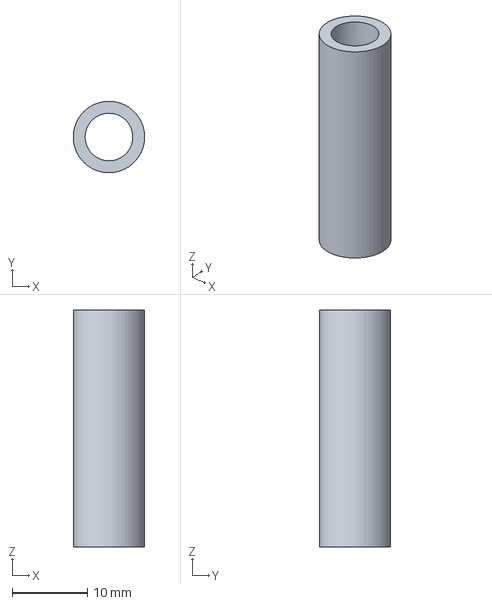
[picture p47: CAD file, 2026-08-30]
Hardware/Chassis2/Mechanical/Fab/HW-C2-DCLMH-450-SPCR-PRINTED-A/HW-C2-DCLMH-450-SPCR-PRINTED-A.step
9.49 x 9.50 x 31.5 mm

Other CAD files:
Hardware/Chassis2/Mechanical/Fab/HW-C2-DCLSPCR-PRINTED-B/HW-C2-DCLSPCR-PRINTED-B.step
Hardware/Chassis2/Mechanical/Fab/HW-C2-FR-BSP-A/HW-C2-FR-BSP-A.step
Hardware/Chassis2/Mechanical/Fab/HW-C2-FR-CLPHLD-A/HW-C2-FR-CLPHLD-A.step
Hardware/Chassis2/Mechanical/Fab/HW-C2-PBB-A/HW-C2-PBB-A.step
Hardware/Chassis2/Boards/DCBusCapacitorBoard/DCBusCapacitorBoard.step
Hardware/Chassis2/Mechanical/Fab/HW-C2-BSP-A/C2-HW-BSP-A.step
Hardware/Chassis2/Mechanical/Fab/HW-C2-BSP-A/HW-C2-BSP-A.stl
Hardware/Chassis2/Mechanical/Fab/HW-C2-CHSP-B/HW-C2-CHSP-B.stl
Hardware/Chassis2/Mechanical/Fab/HW-C2-DCLBB-A/HW-C2-DCLBB-A.stl
Hardware/Chassis2/Mechanical/Fab/HW-C2-DCLMH-200-PRINTED-B/HW-C2-DCLMH-200-PRINTED-B.stl
Hardware/Chassis2/Mechanical/Fab/HW-C2-DCLMH-200-SPCR-PRINTED-A/HW-C2-DCLMH-200-SPCR-PRINTED-A.stl
Hardware/Chassis2/Mechanical/Fab/HW-C2-DCLMH-450-PRINTED-A/HW-C2-DCLMH-450-PRINTED-A.stl
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

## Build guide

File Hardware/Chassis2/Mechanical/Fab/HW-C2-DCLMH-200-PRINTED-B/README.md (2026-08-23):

# DC Link Module Holder - 200V Class

3D-printed part.

## What goes here

- `HW-C2-DCLMH-200-PRINTED-B.step` — CAD model exported from FreeCAD (required)
- `info.png` — render or photo, embedded in the price report (optional)
- `info.txt` — specs and price

## info.txt fields

| Field | Meaning |
|---|---|
| PartName | Human-readable name — drives category detection |
| Material | e.g. PETG, PLA, ABS |
| Thickness_mm | Sheet thickness / part height |
| Qty | Quantity per chassis |
| Dimensions_in / Dimensions_mm | Part dimensions |
| Finish | e.g. as printed, vapor smoothed |
| UnitPrice | USD per part |
| Process | e.g. 3D Printing |
| Notes | Design notes, tolerances |

## Revisions

The revision is part of the part number, in both the folder name and the
FreeCAD body/group label. To bump: rename the label in the FCStd model
(e.g. `...-PRINTED-A` → `...-PRINTED-B`), rename this folder and the STEP
inside it to match, then re-run the extraction (STEP/STL/holes/model_parts
are regenerated from the model). The release pipeline (HWRelease) keys on
the label suffix, so folder name, label, and STEP filename must agree.

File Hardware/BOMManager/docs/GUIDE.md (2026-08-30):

# BOM Manager — Usage Guide

The fab-time tool for this project. It collects the BOM from your KiCad
boards, wiring harnesses, mechanical hardware, and fabricated parts; helps you
price and order everything (with pack-size math and your on-hand stock); and
builds the release package (order files + full PDF report).

## Setup

```bash
cd Hardware/BOMManager
pip install -r requirements.txt
pip install -r requirements-dev.txt   # pytest, for the test suite
python3 -m pytest tests/              # sanity check
```

`config.yaml` (vendor API keys) is optional — everything works on manual
prices and pasted cart/order imports.

## The shell

```bash
python3 bom.py            # interactive
python3 bom.py status     # one-shot (any command works this way)
```

Everything below is a shell command. The shell remembers your chassis
(`chassis <name>` to switch) and never dies on a bad command — fix and retry.

## Daily loop: parts, prices, packs, stock

```text
status                    # dashboard: lines, priced coverage, attention items
parts                     # every BOM line with vendor PN + price status
parts --unpriced          # just what's missing prices
add                       # wizard: walk lines that need entries
price 94669A199 3.10      # set a price (per piece, or per pack if packed)
pack 94669A199 25         # sold in boxes of 25 -> ordering counts packs
stock 94669A199 19        # leftovers on your shelf (local, gitignored)
exclude <query>           # mark a part DNO (do not order)
forget <query>            # delete a part's database entry
```

Rules of thumb:

- **Qty = pieces the design needs**, never packs. `pack` carries the pack
  size; ordering does `ceil((need − stock) / pack_size)`.
- Prices are per **order unit** (per piece normally, per pack when packed).
- The query for price/pack/stock is a vendor PN, internal PN, or description
  text — a picker appears when it's ambiguous.

## MechanicalBOM.txt is owned by the tool

Don't hand-edit it. It holds purchased chassis hardware (any vendor string):

```text
mech                            # list with prices
mech add McMaster 94669A199 12 M3x10 SHCS
mech set 94669A199 6
mech rm 94669A199
```

Board-level parts and harness parts do **not** belong here — those come from
KiCad.

## Boards

Export each board's BOM **from the schematic editor** (Eeschema → Tools →
Generate BOM) as `Boards/<Board>/<Board>.csv` (beside the project). Both the
classic `Id;Designator;Footprint;Quantity;Designation` format and the KiCad
10 `Reference,Qty,Value,DNP,...` export work; DNP/excluded rows are skipped.
`Fab/` holds gerbers/drill — those get zipped for the fab house.

Parts covered elsewhere (e.g. a connector that ships with a harness) should
be **Exclude from BOM** in the schematic so they aren't double-ordered.

```text
fab pcb-price ControlBoard 25.24    # set a board's fab price
import jlcpcb                        # or paste a JLCPCB cart to set them all
```

## Wiring harnesses

One folder per harness under `Wiring/<Name>/`: a KiCad schematic (layout not
needed) plus the schematic BOM export as `<Name>.csv` in the same folder.

```text
new harness GDVSHarness     # scaffolds folder + README + descriptor
```

- Components (connectors, crimps, wire) consolidate into the BOM like any
  other part; the harness itself appears as a `HW-C2-WH-...` assembly line.
- **Descriptor** comes from `new harness`, from the folder name when it's
  IPN-shaped (`HW-C2-WH-GD-A` or `HW-C2-WH-GD` — adopted with no prompt), or
  from a one-time prompt otherwise.
- **Building several per chassis?** The schematic documents ONE harness; add
  `info.txt` with `Qty=4` next to the CSV. The assembly line and all
  components multiply.

Current harnesses as an example: GDVS ×1, TSIGBT ×2, CS ×4, TSBCM ×1.

## Fabricated parts (SendCutSend & friends)

```text
new fab DC Link Bus Bar     # Mechanical/Fab/HW-C2-DCLBB-A/ + info.txt + README
```

Drop the STEP in, fill `info.txt` (or paste a cart into `import sendcutsend`
and it fills material/thickness/price/qty for you). `fab` shows readiness
(STEP ✓, info.txt ✓, price ✓, image ✓) and the same checklist lands in the
report.

## Ordering

```text
release
```

runs the full generate and prints an upload checklist. It also writes
**spares variants** under `FabricationData/BOMs/Variants/`:

- `standard/` — cheap parts (crimps, housings, passives) +25% (min +2)
- `generous/` — cheap parts +50% (min +5), **and** +1 each on medium parts
  ($1–$30: STM32s, NCV57100 gate drivers, gate-drive supplies)

Very expensive parts (IGBTs) and in-house assemblies are never spared. Each
variant directory has the full vendor CSV set + McMaster paste + a priced
Consolidated BOM; the tier totals print for comparison.

| Vendor | File | Where |
|---|---|---|
| Mouser | `BOMs/mouser_bom.csv` | Mouser BOM tool |
| DigiKey | `BOMs/digikey_bom.csv` | DigiKey BOM tool |
| McMaster | `McMaster_Order_Paste.txt` | cart "paste part numbers" box (quantities are packs; stock-covered lines omitted) |
| SendCutSend | `Mechanical/Fab/*/` STEPs | specs in the report |
| PCB | `PCB_Fab_Zips/*.zip` | your PCB vendor |

## Build variants

Distinct from the spares tiers above: a **build variant** is a different
configuration of the same chassis (e.g. a 450 V build that swaps the DC-link
capacitor bank). The schematic stays the design truth; the swap happens at BOM
level via `Hardware/<Chassis>/variants.yaml`:

```yaml
default: 200v            # variant whose outputs land at FabricationData/ root
variants:
  200v:
    description: "200 V class — stock 60x UCS2D331MHD 330uF/200V bank"
    rules: []            # committed tree as-is
  450v:
    description: "450 V class — capacitor swap to 60x UCS2W680MHD 68uF/450V"
    rules:
      - exclude: {designation: UCS2D331MHD}           # case-insensitive exact
      - exclude: {source: HW-C2-DCLMH-200-PRINTED-B}  # board / fab folder name
      - add: {designation: UCS2W680MHD, footprint: CAPPRD750W80D1800H3700,
              category: board, source: DCBusCapacitorBoard, quantity: 60,
              description: "Nichicon 68uF 450V electrolytic"}
      - add: {fab: HW-C2-DCLMH-450-PRINTED-A, quantity: 1}
```

- `exclude` drops items matching a designation (case-insensitive exact) or a
  source (board name / `Mechanical/Fab/` folder name). A rule that matches
  nothing is an error — typos never silently no-op.
- `add` injects a synthetic part; the `add: {fab: FOLDER-NAME, quantity: N}`
  form pulls a `Mechanical/Fab/` folder (specs from its `info.txt`). Such a
  folder is **variant-only**: it stays out of the base BOM and appears only in
  the variants that add it. Descriptions/prices for added parts come from the
  part database like any other line.
- `setqty: {designation: X, quantity: N}` (or `{source: FOLDER, ...}`) changes
  only the quantity of an existing line — e.g. extra washers in one build. It
  shows up as a quantity difference in the comparison report.

`generate` with no `--variant` flag builds **all declared variants at once**.
The `default` variant writes to the usual `FabricationData/` root (paths and
bytes unchanged vs. a chassis with no variants.yaml); other variants write the
same file set to `FabricationData/Builds/<variant>/` (PCB zips skipped — the
boards are identical). Use `--variant 450v` (or a comma list) to build a
subset. The release PDF/QC/labels are built once, for the default variant (or
the single `--variant` if given).

Chassis 2 currently declares three build variants: `200v` (default), `450v`
(capacitor-bank swap), and `dcdc` (C2-DCDC-A — the 15 kW DC/DC converter
build: 450 V class bank plus the choke/coldplate/frame extras from
`Mechanical/DC-DC-Module.FCStd`; orderable outputs under
`FabricationData/Builds/dcdc/`).

After a multi-variant run, the root also gets:

- `Variant_Comparison.md` — per-variant totals plus "only in X" and
  quantity-difference tables with vendor PN/price columns.
- `variants.json` — machine-readable manifest (names, descriptions, output
  dirs, added/removed designations, line counts, totals) for the docs website.

Both stay tracked in git alongside `Pricing_Report.md`; everything else under
`Builds/` is gitignored. Note the two "variants" concepts live in different
places: **build variants** (parts differ) under `FabricationData/Builds/`,
**spares tiers** (only quantities differ) under `FabricationData/BOMs/Variants/`.

## Importing real prices back

After carts/orders exist, import them — prices land in the local cache **and**
the committed part database (so cost history survives a fresh clone):

```text
import mouser ~/Downloads/mouser_bom.xlsx    # BOM-tool xlsx or pasted text
import digikey ~/Downloads/digikey.csv.xlsx  # BOM-tool export
import mcmaster                              # paste order text, Ctrl+D
import jlcpcb                                 # paste cart text (per-board fab prices)
import sendcutsend                            # paste cart text (fills info.txt)
```

The Mouser importer also resolves parts you uploaded by manufacturer PN and
writes the resolved Mouser PNs back into the database, so the next upload is
fully populated. Unmatched lines are reported, not silently dropped.

## Revisions

```text
rev list
rev bump DCLBB --note "widen mounting holes"
```

- Internal PNs (`HW-C2-BB-DCLBB-A`) are identity-keyed — editing descriptions
  or friendly names never renumbers anything.
- Bumping writes `Rev=` into a fab part's `info.txt` and records history
  (rev, date, note) in `part_numbers.json`. **Folders and files are never
  renamed** — CAD and vendor links keep working.
- For PCBs, the rev on the silkscreen is yours to maintain: bump in the tool
  and update the silk text in the same sitting, so boards say what they are.
- When you bump, re-export vendor-facing artifacts (STEP, PDFs) with the new
  rev in the filename.

## Regen: change the design, run one command

```text
regen
```

re-exports everything from KiCad and rebuilds the BOM:

- each board: BOM CSV (`sch export bom`), gerbers + drill into `Fab/`,
  board STEP model, and a DRC report at `FabricationData/DRC/<Board>.txt`
  (**errors only** — warnings are suppressed for now; counts printed per board)
- each harness: BOM CSV from its schematic
- then a normal `generate` runs

The loop is: edit schematics/layout in KiCad → `regen` → order/check the
outputs. `release` afterwards for the PDF + assembly HTML.

## The release PDF

`release` also builds `FabricationData/Release_Report.pdf` (styled after the
project docs, same format as `Docs/HARA.pdf`):

- Cover with totals and the 1/2/3/5/10-unit scaling table
- Contents page, order summary (per-vendor tables, pack-aware)
- Fabrication package (readiness incl. harness qty/rev + a page per fab part
  with a **fresh 3D preview rendered from its STEP file**, colored by material)
- Per board: divider (name, IPN, **3D board renders** top + bottom) →
  **composite front/back views** (the PCB-viewer look: copper + silk + mask)
  → full schematic → PCB layer plots (all copper + silkscreen, drawing sheet
  shows the true plot scale) → **DRC summary page** (errors only, from the
  regen reports)
- Per harness: divider → schematic
- **Design documents**: every document in `Docs/` (HARA, TARA, SWAD, Manual,
  analyses) is a part with its own IPN (`HW-C2-DOC-...`), compiled into the
  package — the PDF you ship with the device.

**Labels** — `FabricationData/Labels.pdf` (or `label` to regenerate alone):
two high-voltage warning labels, a chassis ID label (serial/date/inspector),
and a grid of per-assembly labels in the `InverterGen5 C2` convention
(name, IPN, rev, qty).

**Document standard: all project docs are Markdown** (`Docs/*.md`) compiled by
one template (docgen: cover page, auto-TOC with page numbers, footers, green
HARA style). Edit the `.md`, run `release`, and both `Docs/*.pdf` and the
package pick it up. No HTML, no LaTeX (use Unicode: ×, Δ, ρ, µ, °).

Rendering: board 3D renders and layer plots come from KiCad CLI (flatpak via
`flatpak run --command=kicad-cli org.kicad.KiCad`); fab-part previews are
rendered from STEP with cadquery + matplotlib (no GL needed); documents are
compiled with weasyprint. `bom.py` automatically re-executes itself with the
bundled `.venv` python when one exists, so dependencies always resolve.

## Assembly HTML (iBOM)

`release` also writes `FabricationData/Assembly/<Board>.html` per board — an
interactive assembly view (click a BOM line to highlight its parts on the
board, front/back views). Open in any browser; great for hand-stuffing.

## Cost by assembly & QC forms

The release PDF's **Cost by Assembly** section breaks the BOM down per
sub-assembly (each board, each harness, each fab part, chassis hardware) with
parts counts and per-assembly cost.

`FabricationData/QC_Forms.pdf` — one printable page per sub-assembly: header
(IPN, rev, qty per chassis), a checkbox parts list with per-assembly
quantities, an inspection checklist (per assembly kind), and a
sign-off block (assembled / inspected / signatures) for the assembler.

## Data files

Committed: `part_database.json` (PNs, pack sizes, prices), `part_numbers.json`
(IPNs + revision history), `part_descriptors.json`, `MechanicalBOM.txt`,
fab part folders, harness folders.

Gitignored (local): `config.yaml`, `price_cache.json`, `inventory.json`
(your shelf stock).

## Command cheat sheet

```text
status | parts [--missing|--unpriced|--vendor X|--type Y] [query]
add | price <q> <usd> | pack <q> <size> [price] | stock [q] [n]
mech [add <vendor> <pn> <qty> [desc] | set <pn> <qty> | rm <pn>]
new fab|harness|board [name]
rev list | rev bump <q> [--rev X] [--note "..."]
fab | fab pcb-price <board> <usd>
import mouser|digikey|mcmaster|sendcutsend|jlcpcb [file]
generate [--qty N --spares none|cheap|all --chassis X --no-prompt]
release
exclude <q> | include <q> | forget <q> | chassis [name] | quit
```

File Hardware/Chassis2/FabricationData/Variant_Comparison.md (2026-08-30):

# Build Variant Comparison — Chassis2

Generated by BOMManager from `variants.yaml`. The default variant's outputs live at the `FabricationData/` root; other builds are under `FabricationData/Builds/<variant>/`.

Totals at qty 1:

| Variant | Description | BOM lines | Total |
|---|---|---:|---:|
| 200v (default) | 200 V class — stock 60x UCS2D331MHD 330uF/200V DC-link bank | 118 | $2,149.71 |
| 450v | 450 V class — capacitor swap to 60x UCS2W680MHD 68uF/450V (18x31.5 mm, ~5 mm shorter) | 118 | $2,237.91 |
| dcdc | C2-DCDC-A — 15 kW DC/DC converter build (450 V class): base C2 power stage + Hammond 195C100 choke pair, Boyd 416201U00000G coldplates, TDK MKK DC-link film cap, and frame/cabinet hardware (Mechanical/DC-DC-Module.FCStd) | 136 | $3,513.91 |

## Only in 450v

| Qty | Designation | Description | Vendor P/N | Unit Price | Line Total |
|---:|---|---|---|---:|---:|
| 6 | 94669A193 | 94669A193 | 94669A193 | — | — |
| 1 | DC Link Module Holder - 450V Class | DC Link Module Holder - 450V Class | DC Link Module Holder - 450V Class | — | — |
| 6 | DC Link Module Holder Spacer - Printed (450V Class) | DC Link Module Holder Spacer - Printed (450V Class) | DC Link Module Holder Spacer - Printed (450V Class) | — | — |
| 60 | UCS2W680MHD | UCS2W680MHD | 647-UCS2W680MHD | $3.6300 | $217.80 |

## Only in 200v (removed in 450v)

| Qty | Designation | Description | Vendor P/N | Unit Price | Line Total |
|---:|---|---|---|---:|---:|
| 6 | 94669A196 | 94669A196 | 94669A196 | — | — |
| 1 | DC Link Module Holder - 200V Class | DC Link Module Holder - 200V Class | DC Link Module Holder - 200V Class | — | — |
| 6 | DC Link Module Holder Spacer - Printed | DC Link Module Holder Spacer - Printed | DC Link Module Holder Spacer - Printed | — | — |
| 60 | UCS2D331MHD | UCS2D331MHD | 647-UCS2D331MHD | $2.1600 | $129.60 |

## Quantity differences (200v -> 450v)

| Designation | 200v qty | 450v qty |
|---|---:|---:|
| 98044A224 | 25 | 50 |

## Only in dcdc

| Qty | Designation | Description | Vendor P/N | Unit Price | Line Total |
|---:|---|---|---|---:|---:|
| 4 | 1568A52 | Threaded-hole round pull handle (C2-DCDC-A) | 1568A52 | — | — |
| 2 | 195C100 | Hammond 195C100 DC filter choke, 1 mH 100 A, chassis mount (C2-DCDC-A) | 546-195C100 | $453.0000 | $906.00 |
| 2 | 416201U00000G | Boyd/Aavid 416201U00000G liquid cold plate, 305 mm 6-pass Hi-Contact (C2-DCDC-A) | 532-416201U00000G | $185.0000 | $370.00 |
| 2 | 5891T56 | Accident prevention illustrated label (C2-DCDC-A) | 5891T56 | — | — |
| 12 | 90166A718 | 18-8 stainless flanged hex head screw (lid retention) (C2-DCDC-A) | 90166A718 | — | — |
| 20 | 90720A550 | Heavy duty twist-resistant hex-shaped rivet nut (C2-DCDC-A) | 90720A550 | — | — |
| 8 | 91292A117 | M4-0.7 x 12 mm 18-8 stainless SHCS (handle mounting) (C2-DCDC-A) | 91292A117 | — | — |
| 4 | 91292A137 | M6-1.0 x 20 mm 18-8 stainless SHCS (frame) (C2-DCDC-A) | 91292A137 | — | — |
| 4 | 91292A144 | M6-1.0 x 50 mm 18-8 stainless SHCS (coldplate mounting) (C2-DCDC-A) | 91292A144 | — | — |
| 8 | 91477A141 | M4 18-8 stainless spring lock washer (C2-DCDC-A) | 91477A141 | — | — |
| 8 | 91477A161 | M6 18-8 stainless spring lock washer (C2-DCDC-A) | 91477A161 | — | — |
| 8 | 91828A251 | M6-1.0 18-8 stainless hex nut (C2-DCDC-A) | 91828A251 | — | — |
| 8 | 93475A250 | M6 18-8 stainless general purpose washer (C2-DCDC-A) | 93475A250 | — | — |
| 6 | 94669A193 | 94669A193 | 94669A193 | — | — |
| 1 | B25645A1328K003 | TDK MKK DC-R film capacitor, 3210 uF 1 kV DC, chassis mount (C2-DCDC-A) | 871-B25645A1328K003 | — | — |
| 1 | DC Link Module Holder - 450V Class | DC Link Module Holder - 450V Class | DC Link Module Holder - 450V Class | — | — |
| 6 | DC Link Module Holder Spacer - Printed (450V Class) | DC Link Module Holder Spacer - Printed (450V Class) | DC Link Module Holder Spacer - Printed (450V Class) | — | — |
| 2 | HW-C2-FR-BSP-A | HW-C2-FR-BSP-A | HW-C2-FR-BSP-A | — | — |
| 1 | HW-C2-FR-CLPHLD-A | HW-C2-FR-CLPHLD-A | HW-C2-FR-CLPHLD-A | — | — |
| 4 | HW-C3-FR-CSP-A | HW-C3-FR-CSP-A | HW-C3-FR-CSP-A | — | — |
| 2 | HW-C3-FR-FRNLID-A | HW-C3-FR-FRNLID-A | HW-C3-FR-FRNLID-A | — | — |
| 60 | UCS2W680MHD | UCS2W680MHD | 647-UCS2W680MHD | $3.6300 | $217.80 |

## Only in 200v (removed in dcdc)

| Qty | Designation | Description | Vendor P/N | Unit Price | Line Total |
|---:|---|---|---|---:|---:|
| 6 | 94669A196 | 94669A196 | 94669A196 | — | — |
| 1 | DC Link Module Holder - 200V Class | DC Link Module Holder - 200V Class | DC Link Module Holder - 200V Class | — | — |
| 6 | DC Link Module Holder Spacer - Printed | DC Link Module Holder Spacer - Printed | DC Link Module Holder Spacer - Printed | — | — |
| 60 | UCS2D331MHD | UCS2D331MHD | 647-UCS2D331MHD | $2.1600 | $129.60 |

## Quantity differences (200v -> dcdc)

| Designation | 200v qty | dcdc qty |
|---|---:|---:|
| 98044A224 | 25 | 50 |

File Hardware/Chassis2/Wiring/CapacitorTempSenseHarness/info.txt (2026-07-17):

# Harness build count per chassis (schematic documents ONE harness)
Qty=1

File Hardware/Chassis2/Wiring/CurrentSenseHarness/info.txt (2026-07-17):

# Harness build count per chassis (schematic documents ONE harness)
Qty=4

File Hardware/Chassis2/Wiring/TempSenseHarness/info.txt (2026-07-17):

# Harness build count per chassis (schematic documents ONE harness)
Qty=2

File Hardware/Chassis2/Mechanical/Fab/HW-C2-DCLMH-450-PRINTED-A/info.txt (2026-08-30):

PartName=DC Link Module Holder - 450V Class
Material=Nylon (PA12 or PA6/66)
Thickness_mm=31.50
Qty=1
Dimensions_in=10.906x4.488 in
Finish=as printed
UnitPrice=
Process=3D Printing
Notes=450V-class 3D-printed holder; UCS2W680MHD 18x31.5 mm caps (~5 mm shorter than 200V class). 100% infill.

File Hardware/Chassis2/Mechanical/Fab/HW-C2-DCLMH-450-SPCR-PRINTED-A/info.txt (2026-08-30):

PartName=DC Link Module Holder Spacer - Printed (450V Class)
Material=Nylon (PA12 or PA6/66)
Qty=6
Dimensions_in=0.374x1.240 in
Finish=as printed
Process=3D Printing
Notes=Spacers between DC link bulk cap board and aluminium heatspreader plate; prevent board flexing during tightening. 450V class (~5 mm shorter caps than 200V class).

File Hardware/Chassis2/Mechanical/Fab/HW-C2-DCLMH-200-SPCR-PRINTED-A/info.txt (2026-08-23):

PartName=DC Link Module Holder Spacer - Printed
Material=Nylon (PA12 or PA6/66)
Qty=6
Finish=as printed
Process=3D Printing
Notes=Spacers between DC link bulk cap board and aluminium heatspreader plate; prevent board flexing during tightening.

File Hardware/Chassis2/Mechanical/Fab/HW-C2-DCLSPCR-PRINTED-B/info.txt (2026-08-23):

PartName=HW-C2-DCLSPCR-PRINTED-B
Material=Nylon (PA12 or PA6/66, solid)
Thickness_mm=
Qty=3
Dimensions_in=
Finish=as printed
UnitPrice=
Process=3D Printing
Notes=DC link spacer; 100% infill (solid). See fab_spec.yaml for print spec.

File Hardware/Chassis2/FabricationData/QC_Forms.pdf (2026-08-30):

InverterGen5 C2 — Hardware Release | 1

QUALITY CONTROL — ASSEMBLY SIGN-OFF

# PCB assembly: Control Board

Assembly | PCB assembly | Qty per chassis | 1
Internal P/N | HW-C2-PCB-CTRL-A | Revision | A

## Parts

[ ] | Qty | Description | Part Number
[ ] | 1 | 524265-E | 305-524265-E
[ ] | 8 | 971350581 | 710-971350581
[ ] | 2 | ACT45B-101-2P-TL003 | 810-ACT45B1012PTL003
[ ] | 3 | B2B-XH-AM_LF__SN_ | 306-B2B-XH-AMLFSNP
[ ] | 36 | 100nF 100V | 80-C1210C104K1RAC
[ ] | 21 | 10nF 500V | 187-CL32B103KGFNNNE
[ ] | 7 | 10uF 25V | 187-CL32A106KAULNNE
[ ] | 8 | 1uf 50V | 187-CL32B105KBHNNNE
[ ] | 2 | 2.2uf 1210 100v | 80-C1210C225J1RAUTO
[ ] | 4 | 22pF 50V | 80-C1210C220J5G
[ ] | 2 | 8mhz hc49-4h crystal | 710-830003156B
[ ] | 1 | LTST-C230CKT | 859-LTST-C230CKT
[ ] | 1 | LTST-C230GKT | 859-LTST-C230GKT
[ ] | 1 | STM32H723ZGT6 | 511-STM32H723ZGT6
[ ] | 1 | STM32G474RCT3 | 511-STM32G474RCT3
[ ] | 1 | TSW-110-21-L-D-LL | 200-TSW11021LDLL
[ ] | 1 | TPS389006ADJRTER | 595-TPS389006ADJRTER
[ ] | 27 | 10k 1210 | 603-AC1210JR-0710KL
[ ] | 2 | 120 1210 | 603-AC1210FR-07120RL
[ ] | 9 | 1k 1210 | 603-RC1210FR-071KL
[ ] | 16 | 20k 1210 resistor | 667-ERJ-P14F2002U
[ ] | 16 | Thick Film Resistors - SMD 1/2watt 249Kohms 1% | 71-CRCW1210-249K-E3
[ ] | 1 | 3k 1210 1% | 603-RC1210FR-073KL
[ ] | 2 | 4.7k 1210 | 71-CRCW12104K70FKEAH
[ ] | 1 | 499kohm 1210 resistor | 667-ERJ-P14F4993U
[ ] | 2 | 560ohm 1210 resistor | 667-ERJ-P14F5600U
[ ] | 1 | RD7-12S033R | 737-RD7-12S033R
[ ] | 3 | RKE-1205S_H | 919-RKE-1205S/H
[ ] | 4 | 22-04-1041 | 538-22-04-1041
[ ] | 3 | MM3Z3V0ST1G | 863-MM3Z3V0ST1G
[ ] | 4 | SZMMSZ4678T1G | 863-SZMMSZ4678T1G
[ ] | 1 | MAX22530AWE+ | 700-MAX22530AWE+
[ ] | 4 | ISO1042BDWVR | 595-ISO1042BDWVR

[ ] | Qty | Description | Part Number
[ ] | 1 | CY15B102Q-SXET | 727-CY15B102Q-SXET
[ ] | 1 | ISO1212DBQ | 595-ISO1212DBQ
[ ] | 2 | SSW-103-01-L-D | 200-SSW10301LD
[ ] | 2 | SSW-108-01-L-D | 200-SSW10801LD
[ ] | 1 | SSW-110-01-F-D | SSW-110-01-F-D
[ ] | 1 | STS41A-AWLB-R3 | 403-STS41A-AWLB-R3
[ ] | 5 | Testpoint TH, RED | 534-5000
[ ] | 2 | BTS462TATMA1 | 726-BTS462TATMA1
[ ] | 1 | LT3080IQ#PBF | 584-LT3080IQ#PBF
[ ] | 2 | TS40-66-50-R-260-SMT-TR | 179-TS406650R260S

## Inspection

[ ] | Check
[ ] | Visual inspection — no damage, contamination, or solder splash
[ ] | Solder joints — wetting, no bridges, no tombstoning
[ ] | IC / connector orientation (pin 1 marks match silkscreen)
[ ] | Continuity: no shorts across power rails (12 V, 5 V, 3.3 V)
[ ] | ESD precautions followed during assembly
Assembled by: | Date:
Inspected by: | Date:
Signature: | Signature:

QUALITY CONTROL — ASSEMBLY SIGN-OFF

# PCB assembly: DC Bus Capacitor Board

Assembly | PCB assembly | Qty per chassis | 1
Internal P/N | HW-C2-PCB-DCBUSCAP-A | Revision | A

## Parts

[ ] | Qty | Description | Part Number
[ ] | 8 | 9774030592R | 710-9774030592R
[ ] | 60 | UCS2D331MHD | 647-UCS2D331MHD

## Inspection

[ ] | Check
[ ] | Visual inspection — no damage, contamination, or solder splash
[ ] | Solder joints — wetting, no bridges, no tombstoning
[ ] | IC / connector orientation (pin 1 marks match silkscreen)
[ ] | Continuity: no shorts across power rails (12 V, 5 V, 3.3 V)
[ ] | ESD precautions followed during assembly
Assembled by: | Date:
Inspected by: | Date:
Signature: | Signature:

QUALITY CONTROL — ASSEMBLY SIGN-OFF

# PCB assembly: Filter Board

Assembly | PCB assembly | Qty per chassis | 1
Internal P/N | HW-C2-PCB-DCFLT-A | Revision | A

## Parts

[ ] | Qty | Description | Part Number
[ ] | 1 | 524265-E | 305-524265-E
[ ] | 12 | B58031U9254M062 | 871-B58031U9254M062
[ ] | 6 | MKP1848S61010JY5B | 75-MKP1848S61010JY5B
[ ] | 18 | VY1222M47Y5UQ6TV0 | 72-VY1222M47Y5UQ6TV0

## Inspection

[ ] | Check
[ ] | Visual inspection — no damage, contamination, or solder splash
[ ] | Solder joints — wetting, no bridges, no tombstoning
[ ] | IC / connector orientation (pin 1 marks match silkscreen)
[ ] | Continuity: no shorts across power rails (12 V, 5 V, 3.3 V)
[ ] | ESD precautions followed during assembly
Assembled by: | Date:
Inspected by: | Date:
Signature: | Signature:

QUALITY CONTROL — ASSEMBLY SIGN-OFF

# PCB assembly: Gate Driver Board

Assembly | PCB assembly | Qty per chassis | 1
Internal P/N | HW-C2-PCB-GD-A | Revision | A

## Parts

[ ] | Qty | Description | Part Number
[ ] | 3 | 524265-E | 305-524265-E
[ ] | 8 | 971150581 | 710-971150581
[ ] | 32 | 100nF 100V | 80-C1210C104K1RAC
[ ] | 30 | 10uF 25V | 187-CL32A106KAULNNE
[ ] | 6 | 220pF 100V C0G 1210 | 80-C1210C221J2G
[ ] | 8 | UCM1H101MCL1GS | 647-UCM1H101MCL1GS
[ ] | 6 | STTH112A | 511-STTH112A
[ ] | 1 | LTST-C230CKT | 859-LTST-C230CKT
[ ] | 1 | LTST-C230GKT | 859-LTST-C230GKT
[ ] | 6 | MGJ2D121509MPC-R7 | 580-MGJ2D121509MPCR7
[ ] | 1 | SSW-110-01-F-D | 200-SSW11001FD
[ ] | 2 | 120 1210 | 603-AC1210FR-07120RL
[ ] | 8 | 1k 1210 | 603-RC1210FR-071KL
[ ] | 12 | 2.7 ohm 1210 | 667-ERJ-14BQF2R7U
[ ] | 1 | 220 1210 | 603-RC1210FR-07220RL
[ ] | 2 | 3k 1210 1% | 603-RC1210FR-073KL
[ ] | 1 | 4.7k 1210 | 71-CRCW12104K70FKEAH
[ ] | 2 | MM3Z3V0ST1G | 863-MM3Z3V0ST1G
[ ] | 12 | BAT54WS-7-F | 621-BAT54WS-F
[ ] | 6 | NCV57100DWR2G | 863-NCV57100DWR2G
[ ] | 16 | Testpoint TH, RED | 534-5000
[ ] | 2 | BTS462TATMA1 | 726-BTS462TATMA1

## Inspection

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

Signature: | Signature:

QUALITY CONTROL — ASSEMBLY SIGN-OFF

# PCB assembly: IO Board

Assembly | PCB assembly | Qty per chassis | 1
Internal P/N | HW-C2-PCB-IO-A | Revision | A

## Parts

[ ] | Qty | Description | Part Number
[ ] | 1 | 776231-1 | 571-776231-1
[ ] | 8 | 971250581 | 710-971250581
[ ] | 2 | AWHSH105D00G | 523-AWHSH105D00G
[ ] | 2 | 100nF 100V | 80-C1210C104K1RAC
[ ] | 5 | UCM1H101MCL1GS | 647-UCM1H101MCL1GS
[ ] | 2 | S3N | 512-S3N
[ ] | 1 | EC7BW-110S12 | 418-EC7BW-110S12
[ ] | 1 | MF-RHT200_32-2 | 652-MF-RHT200/32-2
[ ] | 1 | DRDNB21D-7 | 621-DRDNB21D-7
[ ] | 1 | SSW-104-01-L-D | 200-SSW10401LD
[ ] | 1 | BTS462TATMA1 | 726-BTS462TATMA1
[ ] | 2 | TSW-103-18-G-D | 200-TSW10318GD
[ ] | 2 | TSW-108-18-F-D | 200-TSW10818FD
[ ] | 1 | TSW-110-18-T-D | 200-TSW11018TD
[ ] | 1 | UJ2-B-HR-G-V | 179-UJ2-B-HR-G-V

## Inspection

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

QUALITY CONTROL — ASSEMBLY SIGN-OFF

# chassis hardware: Mechanical

Assembly | chassis hardware | Qty per chassis | 1
Internal P/N | — | Revision | A

## Parts

[ ] | Qty | Description | Part Number
[ ] | 1 | 1821A55 | 1821A55
[ ] | 8 | 6926K352 | 6926K352
[ ] | 5 | 6926K56 | 6926K56
[ ] | 1 | 7381K23 | 7381K23
[ ] | 8 | 90128A232 | 90128A232
[ ] | 5 | 90225A102 | 90225A102
[ ] | 4 | 91292A108 | 91292A108
[ ] | 18 | 91292A134 | 91292A134
[ ] | 1 | 91458A112 | 91458A112
[ ] | 6 | 91502A180 | 91502A180
[ ] | 6 | 91502A183 | 91502A183
[ ] | 4 | 92125A228 | 92125A228
[ ] | 4 | 94180A351 | 94180A351
[ ] | 6 | 94669A190 | 94669A190
[ ] | 6 | 94669A196 | 94669A196
[ ] | 12 | 94669A199 | 94669A199
[ ] | 12 | 96738A257 | 96738A257
[ ] | 25 | 98044A224 | 98044A224
[ ] | 1 | 951-GP1500-080-02 | 951-GP1500-080-02
[ ] | 3 | CM600DY-24T (CM600DY-13T recommended for Chassis Size 2 200-450 V; 24T also compatible) | CM600DY-24T

## Inspection

[ ] | Check
[ ] | Correct part and quantity per line
[ ] | Fastener torque per specification
[ ] | Threadlocker applied where required
Assembled by: | Date:
Inspected by: | Date:
Signature: | Signature:

QUALITY CONTROL — ASSEMBLY SIGN-OFF

# Capacitor Temp Sense Wiring Harness

Assembly | wiring harness | Qty per chassis | 1
Internal P/N | HW-C2-WH-TSBCM-A | Revision | A

## Parts

[ ] | Qty | Description | Part Number
[ ] | 1 | 455-2266-ND | 306-XHP-2
[ ] | 1 | NXFT15XH103FEAB021 | 81-NXFT15XH103FEAB21
[ ] | 2 | SXH-001T-P0.6 | 306-SXH-001T-P0.6

## Inspection

[ ] | Check
[ ] | Wire gauges and colors match the schematic
[ ] | Crimp quality — pull test one crimp per connector
[ ] | Pin-to-pin continuity against the schematic
[ ] | Connector keying / locking features engaged
[ ] | Length and routing match the harness drawing
Assembled by: | Date:
Inspected by: | Date:
Signature: | Signature:

QUALITY CONTROL — ASSEMBLY SIGN-OFF

# Current Sensor Wiring Harness

Assembly | wiring harness | Qty per chassis | 4
Internal P/N | HW-C2-WH-CS-A | Revision | A

## Parts

[ ] | Qty | Description | Part Number
[ ] | 8 | 0022011042 | 0022011042
[ ] | 32 | 08-50-0113 | 08-50-0113
[ ] | 4 | LA37S600S05KM | 838-LA37S600S05KM

## Inspection

[ ] | Check
[ ] | Wire gauges and colors match the schematic
[ ] | Crimp quality — pull test one crimp per connector
[ ] | Pin-to-pin continuity against the schematic
[ ] | Connector keying / locking features engaged
[ ] | Length and routing match the harness drawing
Assembled by: | Date:
Inspected by: | Date:
Signature: | Signature:

QUALITY CONTROL — ASSEMBLY SIGN-OFF

# Gate Drive Wiring Harness

Assembly | wiring harness | Qty per chassis | 1
Internal P/N | HW-C2-WH-GDVS-A | Revision | A

## Parts

[ ] | Qty | Description | Part Number
[ ] | 5 | 544959-E | 544959-E
[ ] | 25 | 464762-E | 305-464762
[ ] | 12 | FDFNYD1-110(5) | 161-FDFNYD1-1105

## Inspection

[ ] | Check
[ ] | Wire gauges and colors match the schematic
[ ] | Crimp quality — pull test one crimp per connector
[ ] | Pin-to-pin continuity against the schematic
[ ] | Connector keying / locking features engaged
[ ] | Length and routing match the harness drawing
Assembled by: | Date:
Inspected by: | Date:
Signature: | Signature:

QUALITY CONTROL — ASSEMBLY SIGN-OFF

# IGBT Temperature Wiring Harness

Assembly | wiring harness | Qty per chassis | 2
Internal P/N | HW-C2-WH-TSIGBT-A | Revision | A

## Parts

[ ] | Qty | Description | Part Number
[ ] | 2 | 455-2266-ND | 306-XHP-2
[ ] | 2 | RTS103C1R2M6L201 | 527-RTS103C1R2M6L201
[ ] | 4 | SXH-001T-P0.6 | 306-SXH-001T-P0.6

## Inspection

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

QUALITY CONTROL — ASSEMBLY SIGN-OFF

# fabricated part: HW-C2-BSP-A

Assembly | fabricated part | Qty per chassis | 1
Internal P/N | HW-C2-PLT-BSP-A | Revision | A

## Parts

[ ] | Qty | Description | Part Number
[ ] | 1 | HW-C2-BSP-A | HW-C2-BSP-A

## Inspection

[ ] | Check
[ ] | Dimensions match the drawing / STEP model
[ ] | Edges deburred; finish as specified in info.txt
[ ] | Flatness / bend angles within tolerance
[ ] | Threads and holes checked with mating hardware
Assembled by: | Date:
Inspected by: | Date:
Signature: | Signature:

QUALITY CONTROL — ASSEMBLY SIGN-OFF

# fabricated part: HW-C2-CHSP-B

Assembly | fabricated part | Qty per chassis | 1
Internal P/N | HW-C2-PLT-CHSP-A | Revision | A

## Parts

[ ] | Qty | Description | Part Number
[ ] | 1 | HW-C2-CHSP-B | HW-C2-CHSP-B

## Inspection

[ ] | Check
[ ] | Dimensions match the drawing / STEP model
[ ] | Edges deburred; finish as specified in info.txt
[ ] | Flatness / bend angles within tolerance
[ ] | Threads and holes checked with mating hardware
Assembled by: | Date:
Inspected by: | Date:
Signature: | Signature:

QUALITY CONTROL — ASSEMBLY SIGN-OFF

# fabricated part: HW-C2-DCLBB-A

Assembly | fabricated part | Qty per chassis | 2
Internal P/N | HW-C2-BB-DCLBB-A | Revision | A

## Parts

[ ] | Qty | Description | Part Number
[ ] | 2 | HW-C2-DCLBB-A | HW-C2-DCLBB-A

## Inspection

[ ] | Check
[ ] | Dimensions match the drawing / STEP model
[ ] | Edges deburred; finish as specified in info.txt
[ ] | Flatness / bend angles within tolerance
[ ] | Threads and holes checked with mating hardware
Assembled by: | Date:
Inspected by: | Date:
Signature: | Signature:

QUALITY CONTROL — ASSEMBLY SIGN-OFF

# fabricated part: DC Link Module Holder - 200V Class

Assembly | fabricated part | Qty per chassis | 1
Internal P/N | HW-C2-HW-DC-LINK-MODULE-HOLDER-A | Revision | A

## Parts

[ ] | Qty | Description | Part Number
[ ] | 1 | DC Link Module Holder - 200V Class | DC Link Module Holder - 200V Class

## Inspection

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

QUALITY CONTROL — ASSEMBLY SIGN-OFF

# fabricated part: DC Link Module Holder Spacer - Printed

Assembly | fabricated part | Qty per chassis | 6
Internal P/N | HW-C2-3DP-DC-LINK-MODULE-HOLDER -SP-A | Revision | A

## Parts

[ ] | Qty | Description | Part Number
[ ] | 6 | DC Link Module Holder Spacer - Printed | DC Link Module Holder Spacer -Printed

## Inspection

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

QUALITY CONTROL — ASSEMBLY SIGN-OFF

# fabricated part: DC Link Module Holder - 450V Class

Assembly | fabricated part | Qty per chassis | 1
Internal P/N | — | Revision | A

## Parts

[ ] | Qty | Description | Part Number
[ ] | 1 | dclinkmoduleholder-450vclass

## Inspection

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

QUALITY CONTROL — ASSEMBLY SIGN-OFF

# fabricated part: DC Link Module Holder Spacer - Printed (450V Class)

Assembly | fabricated part | Qty per chassis | 1
Internal P/N | — | Revision | A

## Parts

[ ] | Qty | Description | Part Number
[ ] | 6 | dclinkmoduleholderspacer-printed(450vclass)

## Inspection

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

QUALITY CONTROL — ASSEMBLY SIGN-OFF

# fabricated part: HW-C2-DCLSPCR-PRINTED-B

Assembly | fabricated part | Qty per chassis | 3
Internal P/N | HW-C2-3DP-DCLSPCR-PRINTED-A | Revision | A

## Parts

[ ] | Qty | Description | Part Number
[ ] | 3 | HW-C2-DCLSPCR-PRINTED-B | HW-C2-DCLSPCR-PRINTED-B

## Inspection

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

QUALITY CONTROL — ASSEMBLY SIGN-OFF

# fabricated part: HW-C2-FR-BSP-A

Assembly | fabricated part | Qty per chassis | 1
Internal P/N | — | Revision | A

## Parts

[ ] | Qty | Description | Part Number
[ ] | 2 | hw-c2-fr-bsp-a

## Inspection

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

QUALITY CONTROL — ASSEMBLY SIGN-OFF

# fabricated part: HW-C2-FR-CLPHLD-A

Assembly | fabricated part | Qty per chassis | 1
Internal P/N | — | Revision | A

## Parts

[ ] | Qty | Description | Part Number
[ ] | 1 | hw-c2-fr-clphld-a

## Inspection

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

QUALITY CONTROL — ASSEMBLY SIGN-OFF

# fabricated part: HW-C2-PBB-A

Assembly | fabricated part | Qty per chassis | 3
Internal P/N | HW-C2-BB-PBB-A | Revision | A

## Parts

[ ] | Qty | Description | Part Number
[ ] | 3 | HW-C2-PBB-A | HW-C2-PBB-A

## Inspection

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

QUALITY CONTROL — ASSEMBLY SIGN-OFF

# fabricated part: HW-C2-SHELL-PRINTED-A

Assembly | fabricated part | Qty per chassis | 1
Internal P/N | HW-C2-3DP-SHELL-PRINTED-A | Revision | A

## Parts

[ ] | Qty | Description | Part Number
[ ] | 1 | HW-C2-SHELL-PRINTED-A | HW-C2-SHELL-PRINTED-A

## Inspection

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

QUALITY CONTROL — ASSEMBLY SIGN-OFF

# fabricated part: Thermal Pad Cutting Stencil

Assembly | fabricated part | Qty per chassis | 1
Internal P/N | HW-C2-HW-THERMAL-PAD-CUTTING-ST EN-A | Revision | A

## Parts

[ ] | Qty | Description | Part Number
[ ] | 1 | Thermal Pad Cutting Stencil | Thermal Pad Cutting Stencil

## Inspection

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

QUALITY CONTROL — ASSEMBLY SIGN-OFF

# fabricated part: HW-C3-FR-CSP-A

Assembly | fabricated part | Qty per chassis | 1
Internal P/N | — | Revision | A

## Parts

[ ] | Qty | Description | Part Number
[ ] | 4 | hw-c3-fr-csp-a

## Inspection

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

QUALITY CONTROL — ASSEMBLY SIGN-OFF

# fabricated part: HW-C3-FR-FRNLID-A

Assembly | fabricated part | Qty per chassis | 1
Internal P/N | — | Revision | A

## Parts

[ ] | Qty | Description | Part Number
[ ] | 2 | hw-c3-fr-frnlid-a

## Inspection

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

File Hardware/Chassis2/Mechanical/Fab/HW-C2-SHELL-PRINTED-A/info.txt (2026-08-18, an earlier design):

PartName=HW-C2-SHELL-PRINTED-A
Material=Nylon (PA12 or PA6/66, solid)
Thickness_mm=
Qty=1
Dimensions_in=
Finish=as printed
UnitPrice=
Process=3D Printing
Notes=Chassis shell; 100% infill (solid). See fab_spec.yaml for print spec.

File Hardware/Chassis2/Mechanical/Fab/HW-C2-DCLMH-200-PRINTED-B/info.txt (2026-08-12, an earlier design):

PartName=DC Link Module Holder - 200V Class
Material=
Thickness_mm=35.50
Qty=1
Dimensions_in=6.000x3.000 in
Finish=as printed
UnitPrice=
Process=3D Printing
Notes=200V-class 3D-printed variant placeholder; 35.5 mm tall caps. Replace with actual design before release.

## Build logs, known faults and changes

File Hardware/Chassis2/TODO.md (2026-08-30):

# Chassis 2 TODOs

- [ ] Evaluate Belleville washers for vibration resistance on motorcycle-mounted inverter fasteners.
  - Context: Loctite 242 was added to the mechanical BOM for thread locking, but a high-vibration motorcycle environment may need Belleville washers or a stronger threadlocker (e.g., Loctite 243/272) on critical fasteners.
  - Decide before releasing the mechanical BOM / assembly docs.

- [x] Fix and finalize internal part numbers for the DC link module holders.
  - Current placeholders: `HW-C2-DCLMH-200-PRINTED-B` and `HW-C2-DCLMH-450-PRINTED-A`.
  - `HW-C2-DCLMH-200-PRINTED-B` is registered (`part_numbers.json`); the 450V
    placeholder folder now exists under `Mechanical/Fab/` and is wired into the
    `450v` build variant in `variants.yaml` (variant-only folder — stays out of
    the 200v BOM; its IPN is assigned on the next `generate` run).
  - Done with the C2-DCDC-A release: `python3 bom.py generate` ran and the IPNs are registered.

- [x] Design actual DC link module holder geometry in FreeCAD.
  - 200V variant uses 35.5 mm tall caps.
  - 450V variant uses shorter caps (~5 mm shorter than 200V).
  - Done for C2-DCDC-A: STEP/STL/holes.json/renders exported from the model into
    `Mechanical/Fab/HW-C2-DCLMH-450-PRINTED-A/` and
    `Mechanical/Fab/HW-C2-DCLMH-450-SPCR-PRINTED-A/`; `info.txt` filled in
    (Thickness_mm=31.50 for the 450V holder).
  - Standoff (94669A196 -> 94669A193) and cap-spacer swap rules are live in the
    `450v` build variant in `variants.yaml` (also carried into the `dcdc` variant).
  - Thermal calcs will vary with aluminum heat-spreader plate thickness per voltage class.

- [ ] DC/DC converter module (C2-DCDC-A) follow-ups.
  - Released as the `dcdc` build variant (`variants.yaml`); orderable outputs in
    `FabricationData/Builds/dcdc/`; full assembly model `Mechanical/DC-DC-Module.FCStd`
    (+ exported `DC-DC-Module.step`).
  - Prices still missing for the Hammond 195C100 chokes, Boyd 416201U00000G
    coldplates, TDK B25645A1328K003 film cap, and the new McMaster frame
    fasteners — set with `bom> price <pn> <usd>` or import a cart.

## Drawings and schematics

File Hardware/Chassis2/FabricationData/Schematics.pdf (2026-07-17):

1 | 2 | 3 | 4 | 5

AB

C

D

AB

C

D Date: 2026-07-07

KiCad E.D.A. 10.0.3

Size: USLetter | Rev: A Id: 1/21

## Title: Open Inverter Platform - Control Board

File: ControlBoard.kicad_sch

Sheet: /

Corzine Lab, University of California, Santa Cruz

Prepared by Thomas Liao

HW-C2-PCB-CTRL GND

SIG1_IN SIG1_OUT SIG2_IN SIG2_OUT SIG3_IN SIG3_OUT SIG4_IN SIG4_OUT

Voltage Divider Network1

File: VDivNet.kicad_sch | +3.3V_A DIN_1_A DIN_1_B DIN_2_A DIN_2_B DIN_3_A DIN_3_B DIN_4_A DIN_4_B DIN_5_A DIN_5_B DIN_6_A DIN_6_B DIN_7_A DIN_7_B DIN_8_A DIN_8_B

GND_A GND_B

Isolated Digital IO

File: IsolatedDigitalIO.kicad_sch GND

SIG1_IN SIG1_OUT SIG2_IN SIG2_OUT SIG3_IN SIG3_OUT SIG4_IN SIG4_OUT

Voltage Divider Network File: VDivNet.kicad_sch GND_A +3.3V_OUT_A +12V_OUT_A +5V_A | +12V_IN +12V_SWITCHED_A SIGNAL_12V_ENABLE_A +12V_CANBUS_A CANBUS_12V_ENABLE_A Power File: Power.kicad_sch | +¹²V_A +³.3V_A CAN_L_B CAN_H_B CAN_GND CAN_5V | CAN_JUMPER_A CAN_JUMPER_B GND_A B_CAN_TX B_CAN_RX A_CAN_TX A_CAN_RX CAN Transciever1 | File: CANTransciever.kicad_sch | +3.3V_A GND_A SPI_SCK_A

ADC1_CS_A VSENSE_DC_LINK_B

VSENSE_GND_B

VSENSE_PH_U_B

VSENSE_PH_V_B

VSENSE_PH_W_B

ADC1_INT_A SPI_MISO_A SPI_MOSI_A

ADC

File: ADC2.kicad_sch GND

SIG1_IN SIG1_OUT SIG2_IN SIG2_OUT SIG3_IN SIG3_OUT SIG4_IN SIG4_OUT

Voltage Divider Network2

File: VDivNet.kicad_sch | +¹²V_A +³.3V_A CAN_L_B CAN_H_B CAN_GND CAN_5V | CAN_JUMPER_A CAN_JUMPER_B GND_A B_CAN_TX B_CAN_RX A_CAN_TX A_CAN_RX CAN Transciever | File: CANTransciever.kicad_sch

GND

SIG1_IN SIG1_OUT SIG2_IN SIG2_OUT Voltage Divider Network3
File: VDivNetHalf.kicad_sch | +3.3V_A GND_A GND_ANALOG_A | CP_BOOT_SEL CP_DEBUG_JTCK_SWCLK CP_DEBUG_JTMS_SWDIO CP_FDCAN2_TX CP_FDCAN2_RX | CP_FDCAN3_TX CP_FDCAN3_RX | CP_GATE_DRIVE_PWR2_ENABLE CP_RESET | CP_USB_DM
CP_USB_DP MP_BOOT_SEL | MP_CANBUS_12V_POWER_ENABLE MP_DEBUG_JTCK_SWCLK MP_DEBUG_JTCK_SWDIO MP_DEBUG_NJTRST MP_DEBUG_SWO MP_DEBUG_TRGIO MP_FDCAN2_TX MP_FDCAN2_RX | MP_FDCAN1_TX MP_FDCAN1_RX | MP_GATE_DRIVE_PWR1_ENABLE MP_PERIPHERAL_POWER_ENABLE MP_RESET | MP_SPI2_CS MP_SPI2_MISO MP_SPI2_MOSI MP_SPI2_SCK MP_TEMP_SENSE_2 MP_TEMP_SENSE_3 | MP_USER_DIN_5 MP_USER_DIN_6 MP_USER_DIN_7 MP_USER_DIN_8 MP_USER_DOUT_1 MP_USER_DOUT_2 MP_USER_DOUT_3 MP_USER_DOUT_4 MP_VSENSE_ISO_ADC_INTERRUPT SN_CUR_SENSE_DC_LINK_REF SN_CUR_SENSE_DC_LINK_SIG

SN_CUR_SENSE_PH_U_REF SN_CUR_SENSE_PH_U_SIG

SN_CUR_SENSE_PH_V_REF SN_CUR_SENSE_PH_V_SIG

SN_CUR_SENSE_PH_W_REF SN_CUR_SENSE_PH_W_SIG

SN_GATE_DRIVE_FAULT SN_GATE_DRIVE_PWR2_FB SN_GATE_DRIVE_PWR1_FB | SN_GATE_DRIVE_READY SN_GATE_DRIVE_RESET SN_HALL_U_ENCODER_SIN

SN_HALL_V_ENCODER_COS
SN_HALL_W

SN_MOTOR_TEMP

SN_PH_U_HIGH
SN_PH_U_LOW
SN_PH_V_HIGH
SN_PH_V_LOW
SN_PH_W_HIGH
SN_PH_W_LOW

SN_TEMP_SENSE_1

SN_THROTTLE_A SN_THROTTLE_B | SN_USER_DIN_1 SN_USER_DIN_2 SN_USER_DIN_3 SN_USER_DIN_4 +5V_A +5V_ISENSE_A +12V_A | MULTIDRIVE_FIBER_SYNC MULTIDRIVE_FIBER_UART_RX MULTIDRIVE_FIBER_UART_TX Control File: Control.kicad_sch | GND_V HEATSINK_TMP2_V HEATSINK_TMP3_V HEATSINK_TMP_V | +3.3V_V MOTOR_TEMP_IN MOTOR_TEMP_V

TemperatureSensors File: TemperatureSensors.kicad_sch DC_LINK_CURSENS DC_LINK_CURSENS_REF GND

PH_U_CURSENS PH_U_CURSENS_REF PH_V_CURSENS PH_V_CURSENS_REF PH_W_CURSENS PH_W_CURSENS_REF +12V_A +5V_ISENSE_A Current Sensors File: CurrentSensors.kicad_sch H2 971350581

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
10 | 11
| 12

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
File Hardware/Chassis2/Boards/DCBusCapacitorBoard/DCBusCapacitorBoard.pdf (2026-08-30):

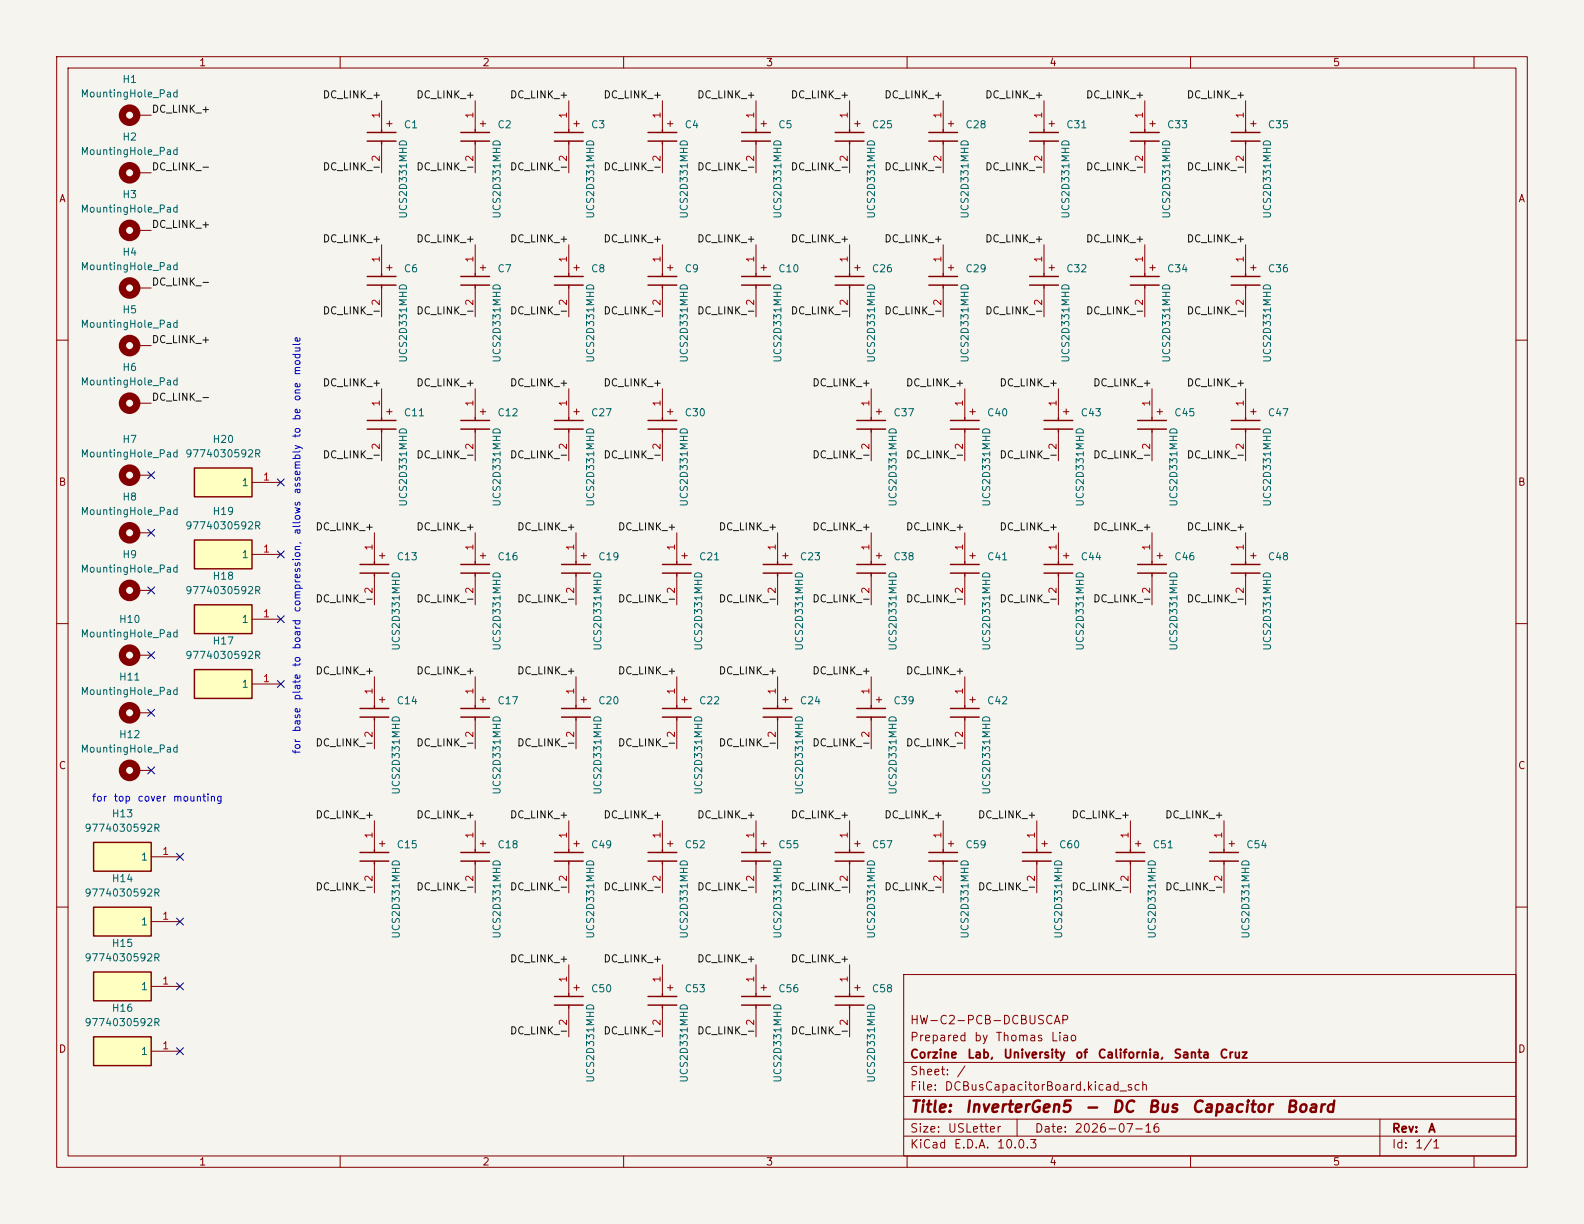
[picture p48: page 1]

DC_LINK_- for base plate to board compression, allows assembly to be one module

for top cover mounting

HW-C2-PCB-DCBUSCAP
Prepared by Thomas Liao
Corzine Lab, University of California, Santa Cruz
Sheet: /
File: DCBusCapacitorBoard.kicad_sch
Title: InverterGen5 - DC Bus Capacitor Board

Size: USLetter | Rev: A
KiCad E.D.A. 10.0.3 | Id: 1/1

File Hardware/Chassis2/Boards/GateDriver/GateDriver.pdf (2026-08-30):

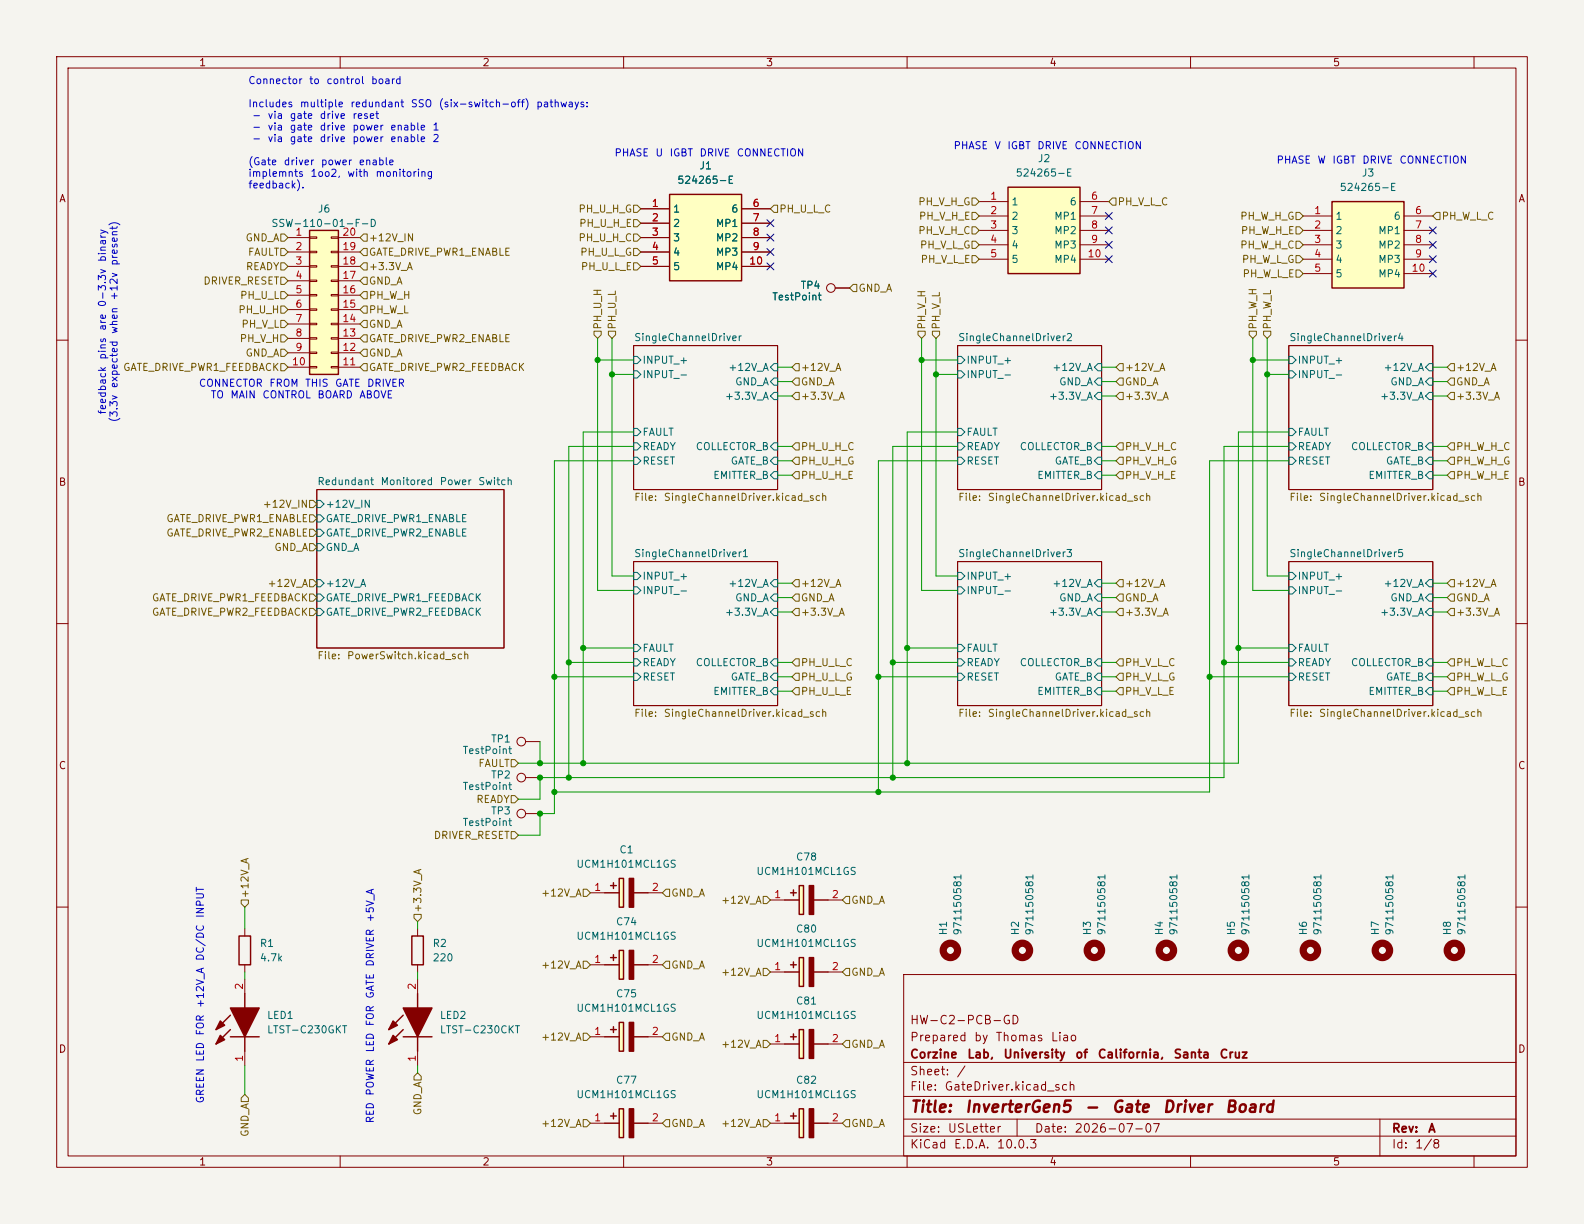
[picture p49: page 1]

Includes multiple redundant SSO (six-switch-off) pathways: - via gate drive reset - via gate drive power enable 1 - via gate drive power enable 2

(Gate driver power enable
implemnts 1oo2, with monitoring

PHASE W IGBT DRIVE CONNECTION

CONNECTOR FROM THIS GATE DRIVER

Prepared by Thomas Liao
Corzine Lab, University of California, Santa Cruz
Sheet: /
File: GateDriver.kicad_sch
Title: InverterGen5 - Gate Driver Board

Size: USLetter | Rev: A
KiCad E.D.A. 10.0.3 | Id: 1/8

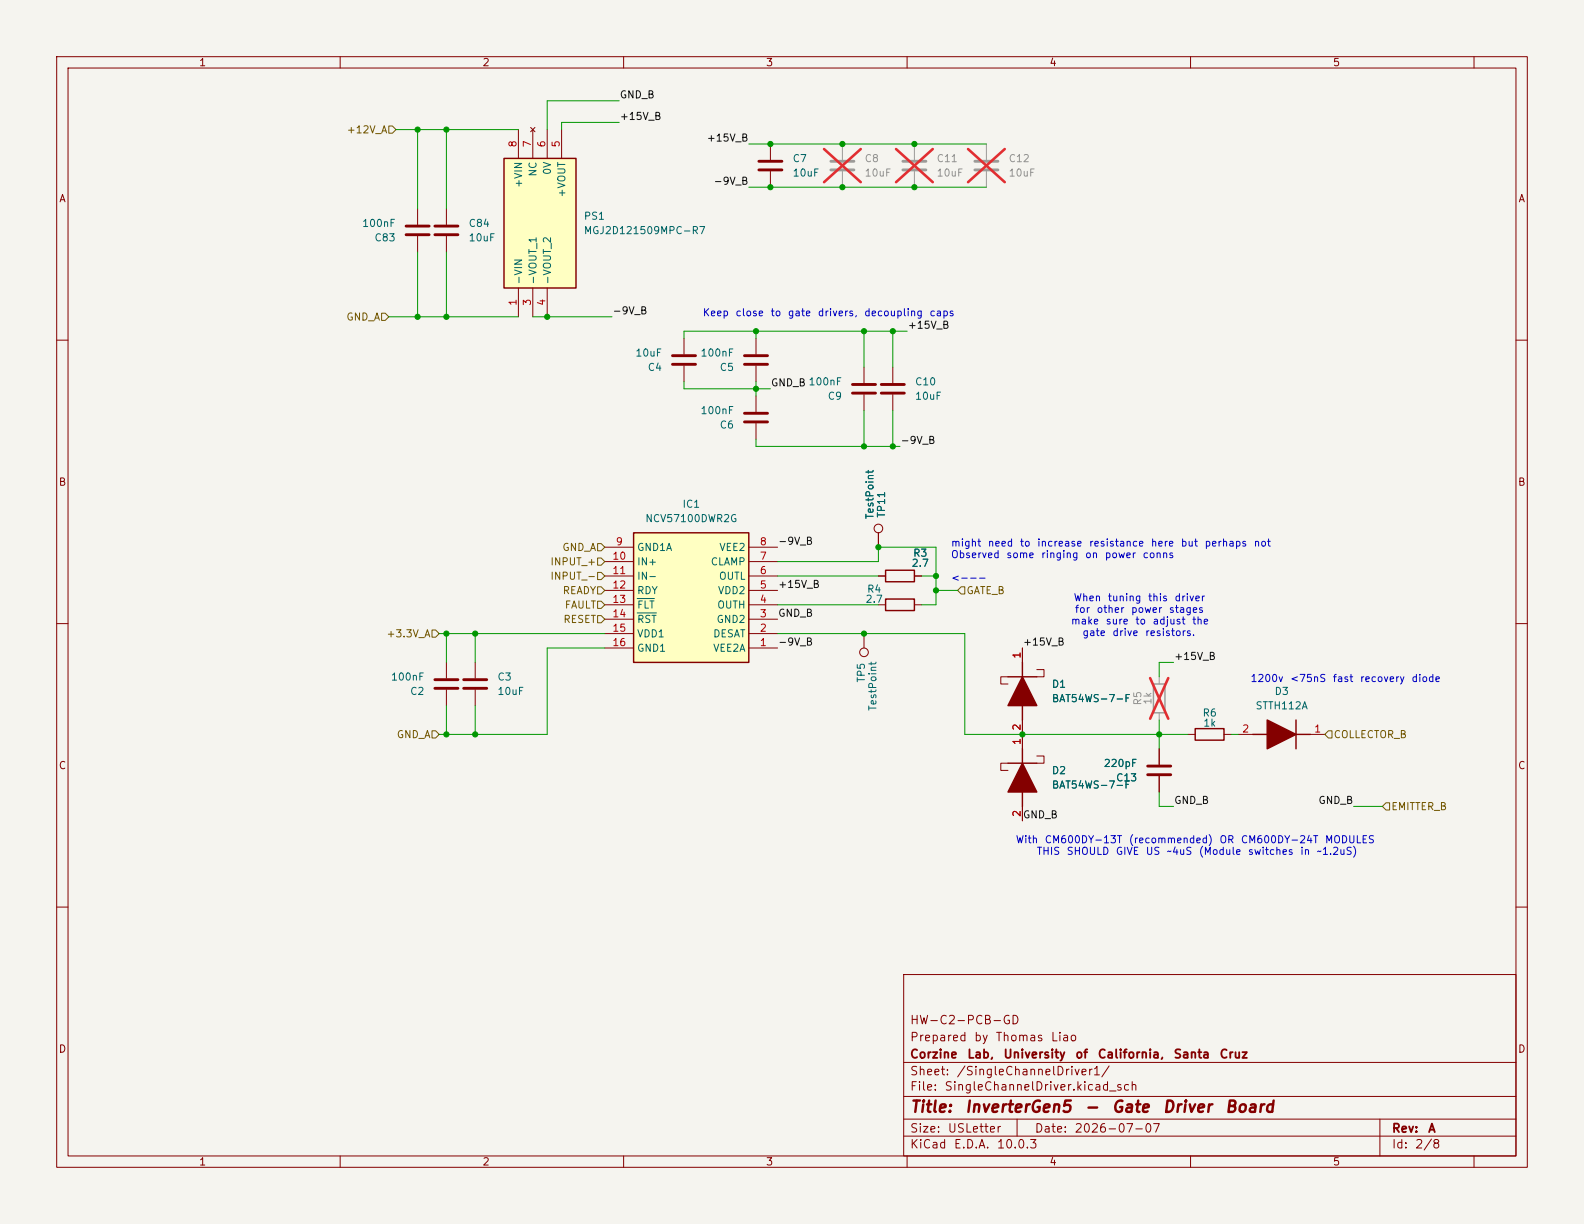
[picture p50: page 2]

GND_B When tuning this driver

With CM600DY-13T (recommended) OR CM600DY-24T MODULES

HW-C2-PCB-GD
Prepared by Thomas Liao
Corzine Lab, University of California, Santa Cruz
Sheet: /SingleChannelDriver1/
File: SingleChannelDriver.kicad_sch
Title: InverterGen5 - Gate Driver Board

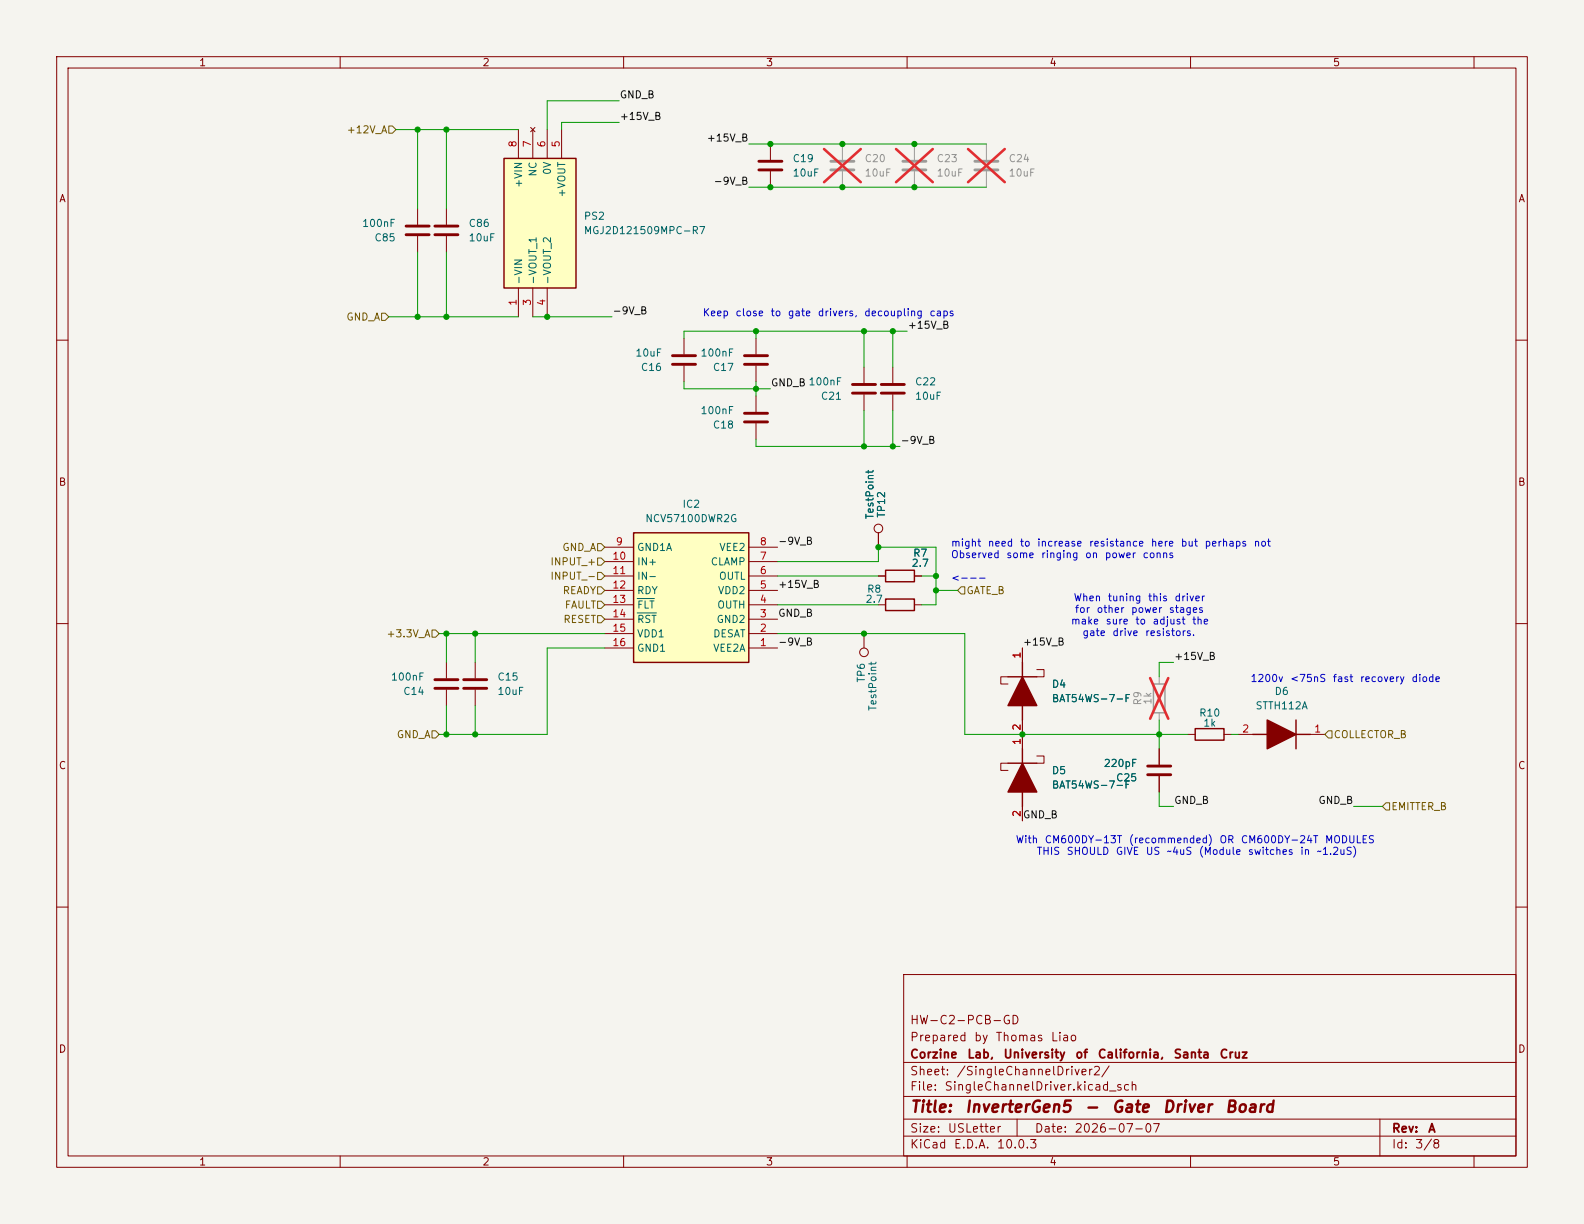
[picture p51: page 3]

THIS SHOULD GIVE US ~4uS (Module switches in ~1.2uS) D4BAT54WS-7-F 1 2 R7

GND_B When tuning this driver

With CM600DY-13T (recommended) OR CM600DY-24T MODULES

HW-C2-PCB-GD
Prepared by Thomas Liao
Corzine Lab, University of California, Santa Cruz
Sheet: /SingleChannelDriver2/
File: SingleChannelDriver.kicad_sch
Title: InverterGen5 - Gate Driver Board

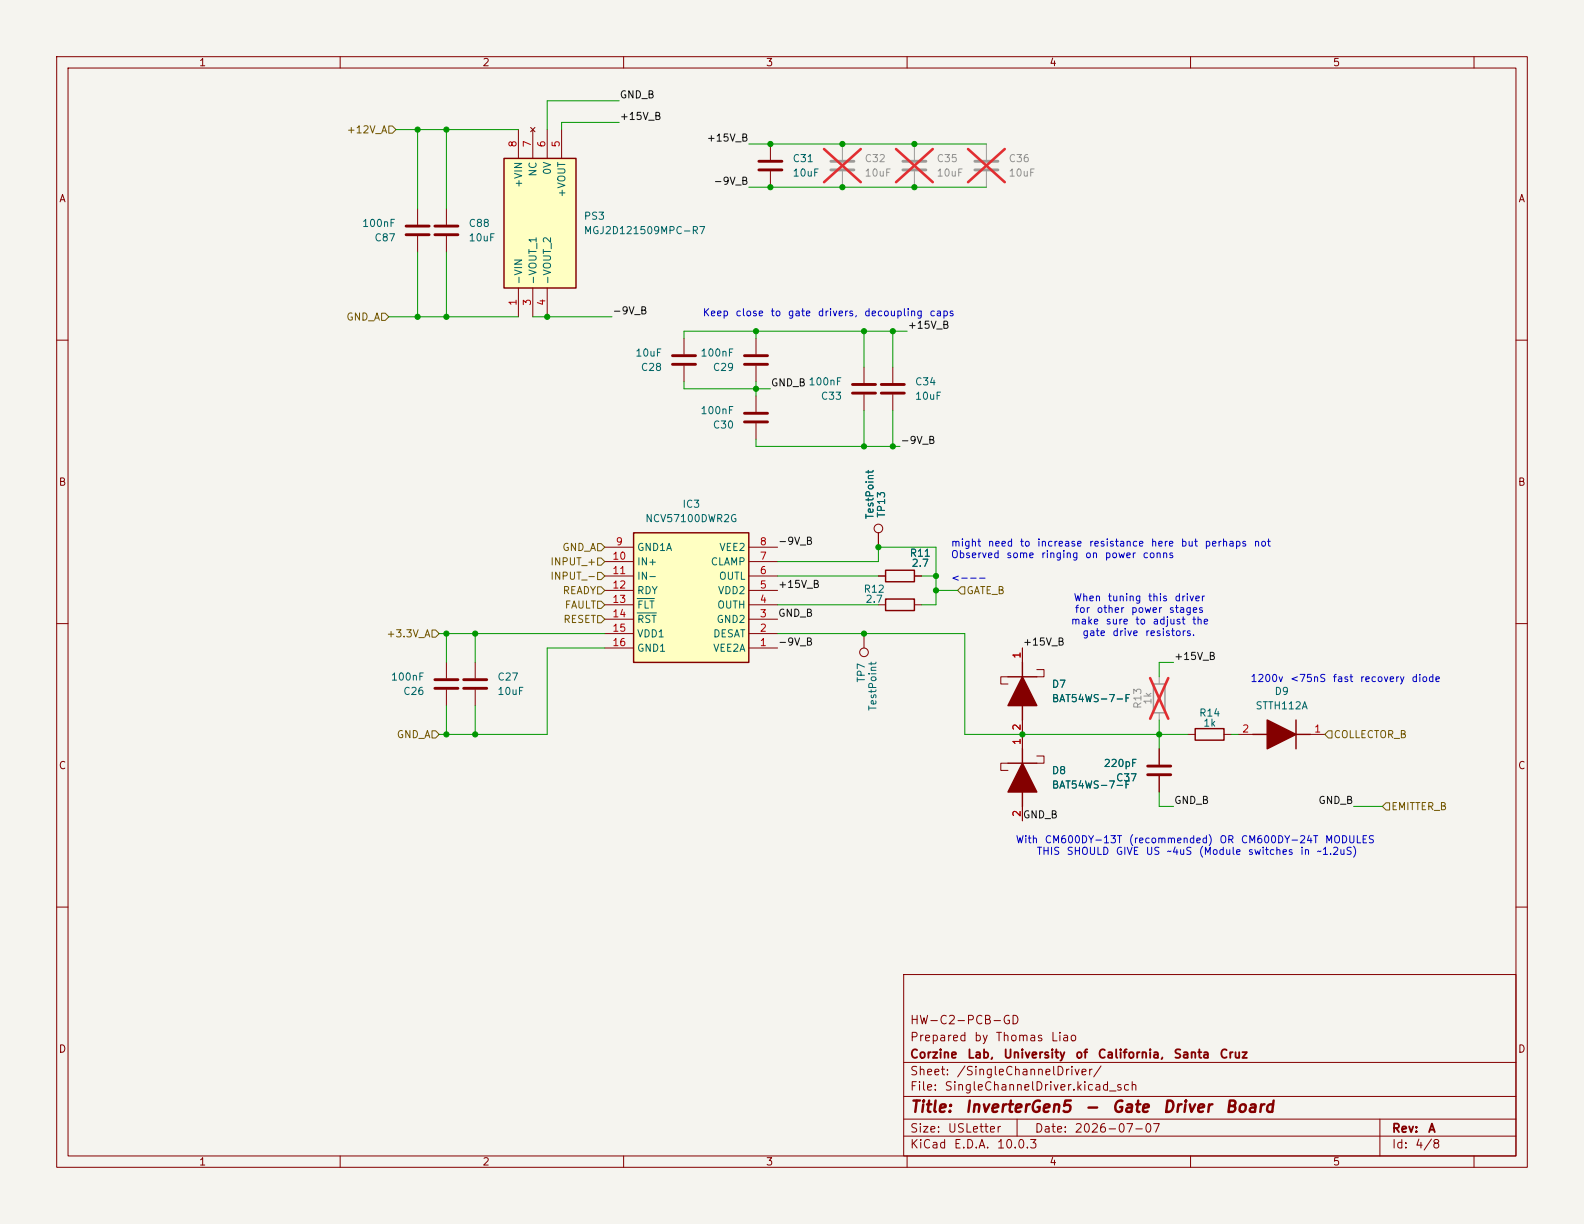
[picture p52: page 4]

GND_B When tuning this driver

With CM600DY-13T (recommended) OR CM600DY-24T MODULES

HW-C2-PCB-GD
Prepared by Thomas Liao
Corzine Lab, University of California, Santa Cruz
Sheet: /SingleChannelDriver/
File: SingleChannelDriver.kicad_sch
Title: InverterGen5 - Gate Driver Board

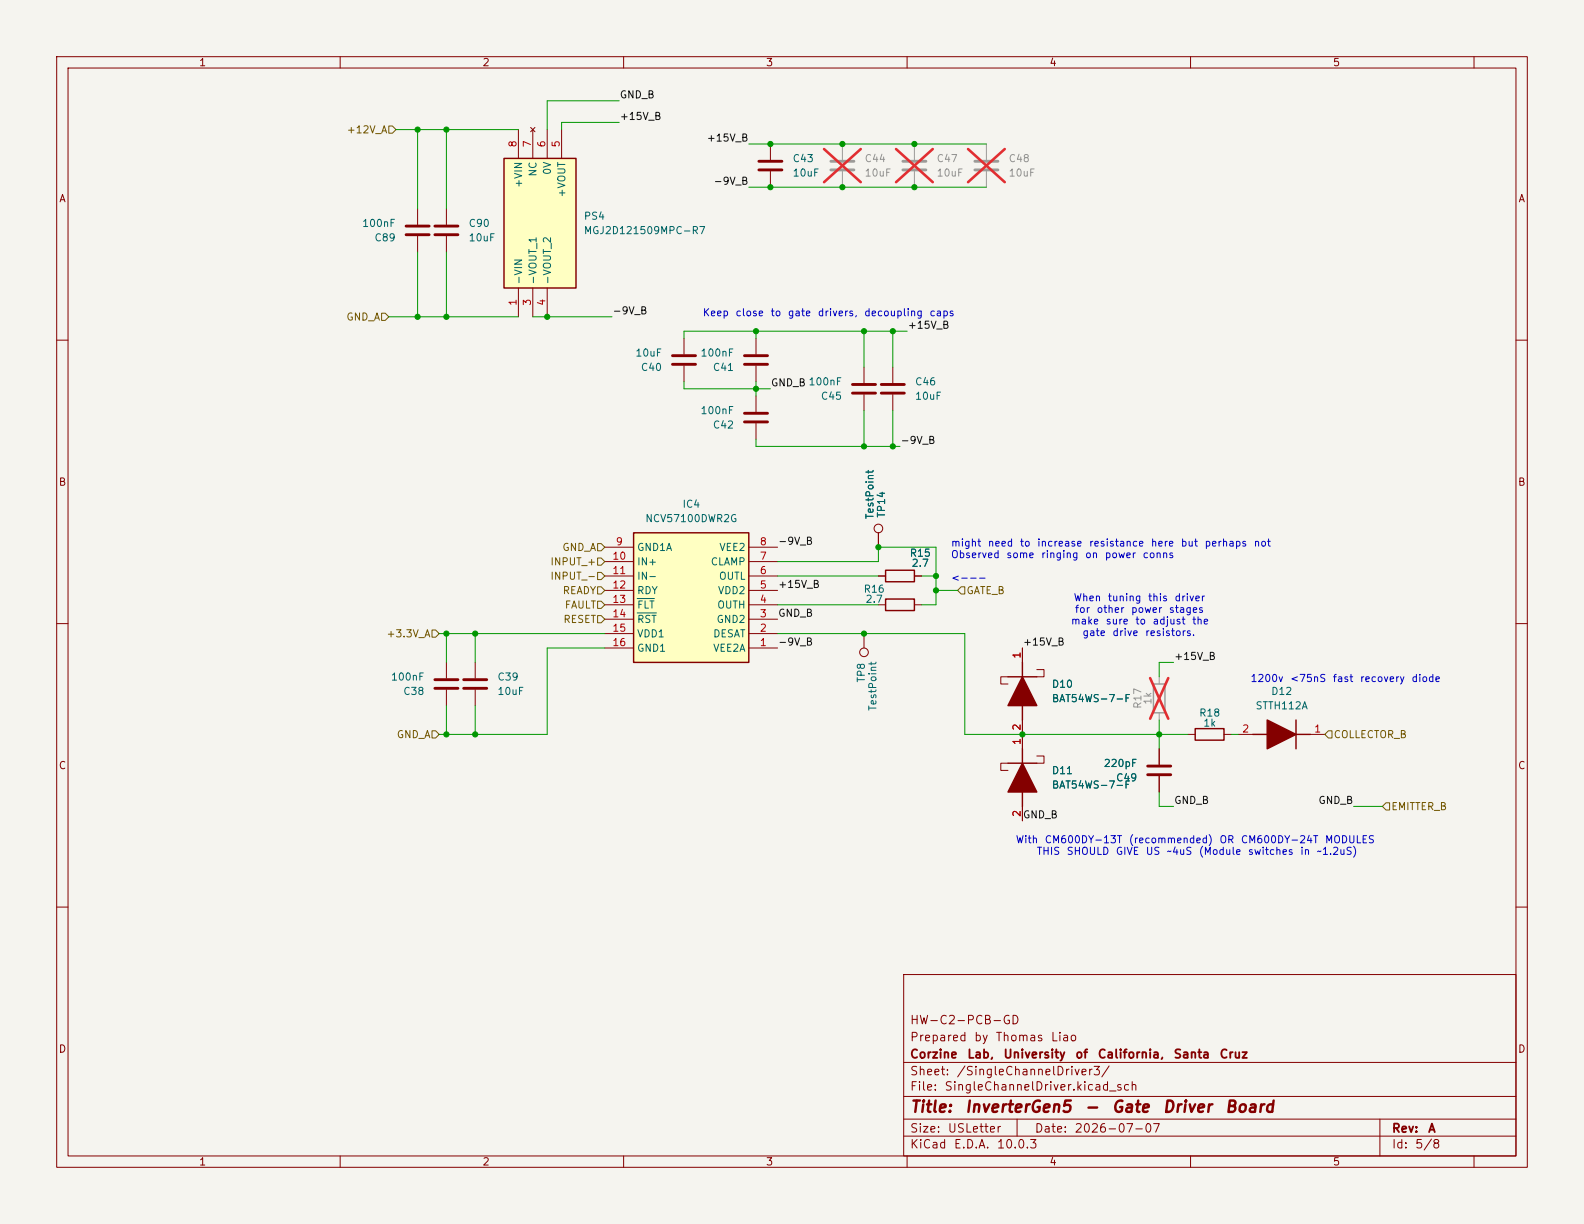
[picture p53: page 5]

THIS SHOULD GIVE US ~4uS (Module switches in ~1.2uS) D10 BAT54WS-7-F 1 2 R15

GND_B When tuning this driver

With CM600DY-13T (recommended) OR CM600DY-24T MODULES

HW-C2-PCB-GD
Prepared by Thomas Liao
Corzine Lab, University of California, Santa Cruz
Sheet: /SingleChannelDriver3/
File: SingleChannelDriver.kicad_sch
Title: InverterGen5 - Gate Driver Board

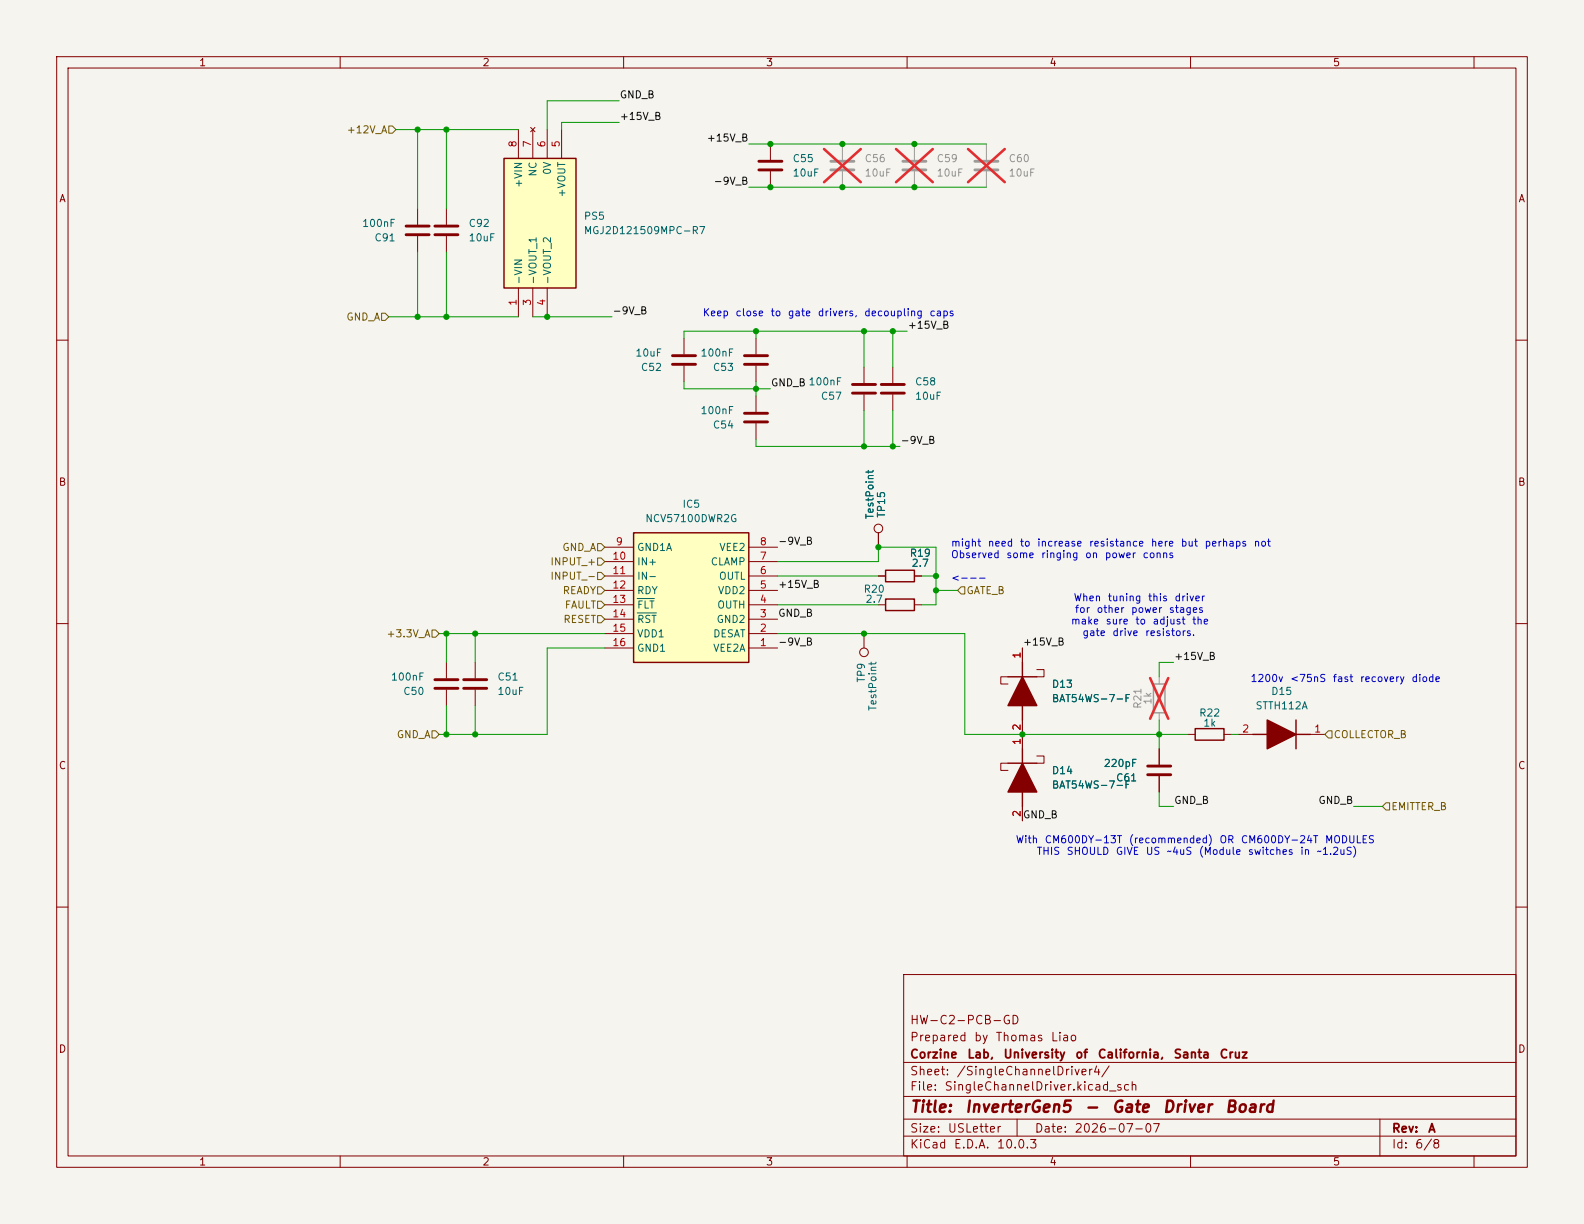
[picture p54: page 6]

GND_B When tuning this driver

With CM600DY-13T (recommended) OR CM600DY-24T MODULES

HW-C2-PCB-GD
Prepared by Thomas Liao
Corzine Lab, University of California, Santa Cruz
Sheet: /SingleChannelDriver4/
File: SingleChannelDriver.kicad_sch
Title: InverterGen5 - Gate Driver Board

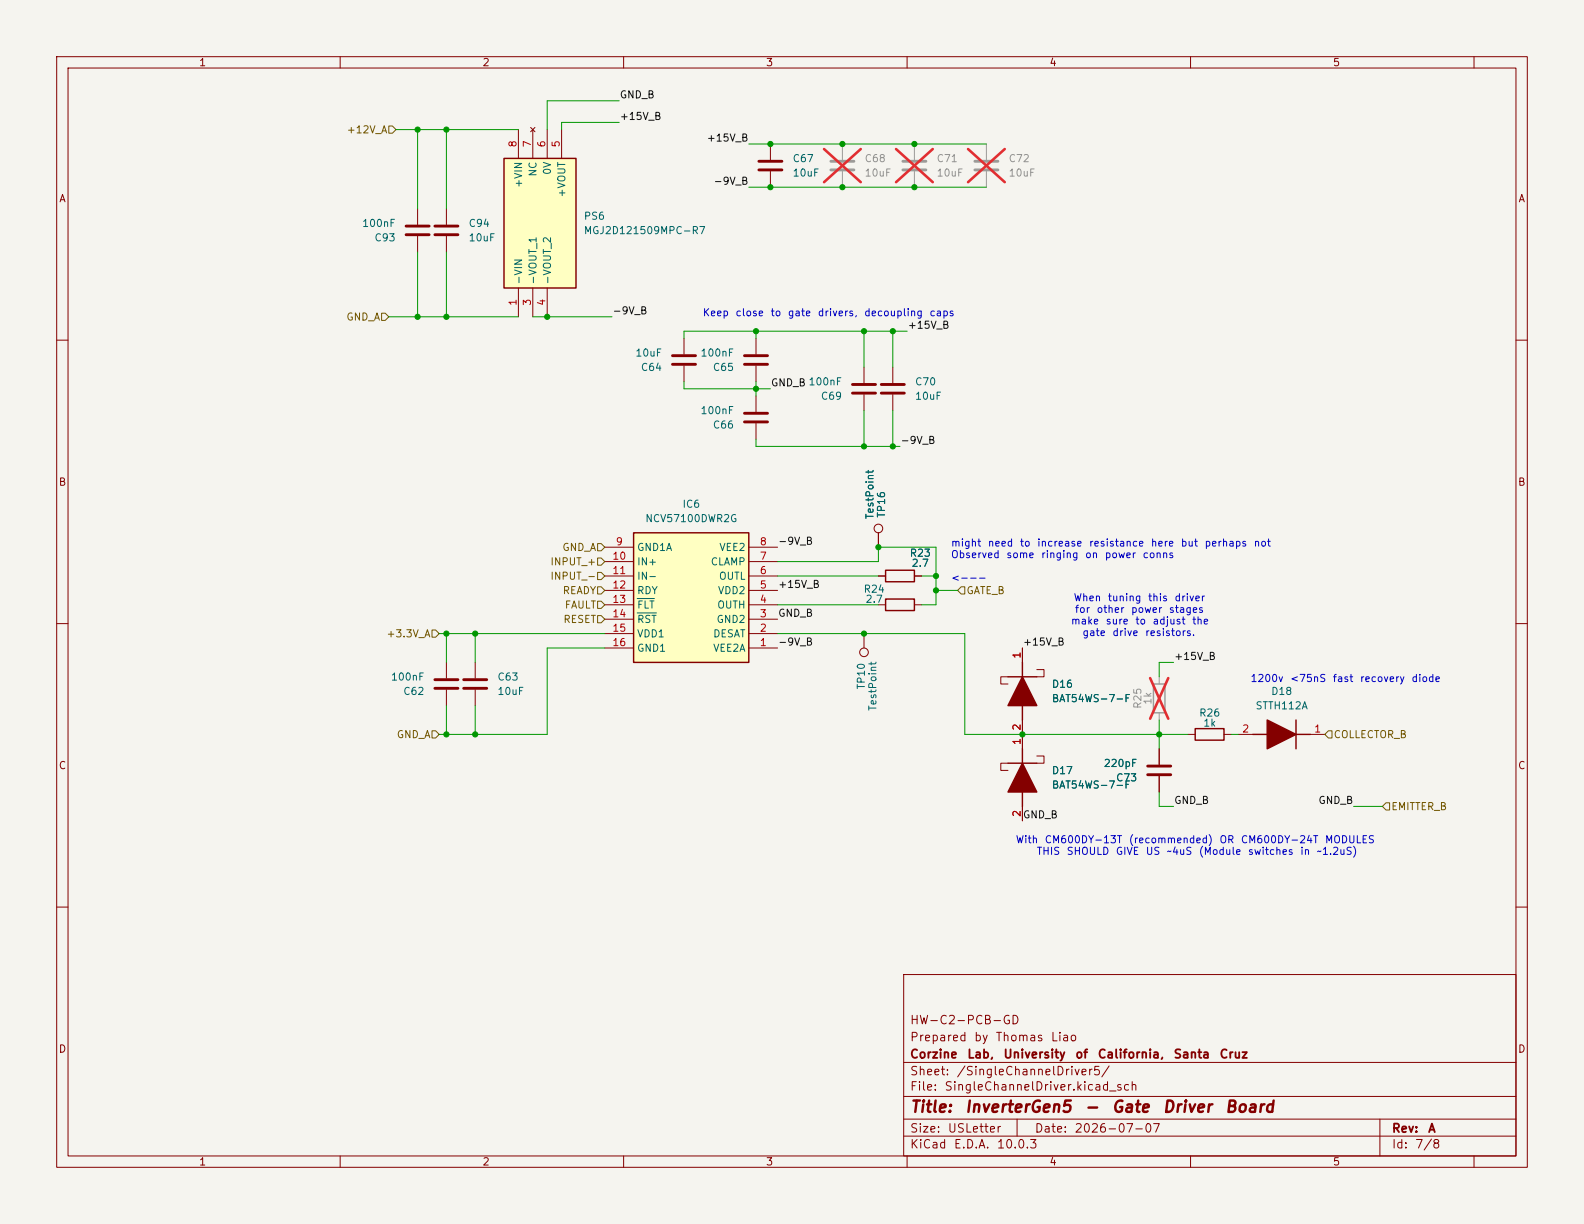
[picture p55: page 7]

THIS SHOULD GIVE US ~4uS (Module switches in ~1.2uS) D16 BAT54WS-7-F 1 2 R23

GND_B When tuning this driver

With CM600DY-13T (recommended) OR CM600DY-24T MODULES

HW-C2-PCB-GD
Prepared by Thomas Liao
Corzine Lab, University of California, Santa Cruz
Sheet: /SingleChannelDriver5/
File: SingleChannelDriver.kicad_sch
Title: InverterGen5 - Gate Driver Board

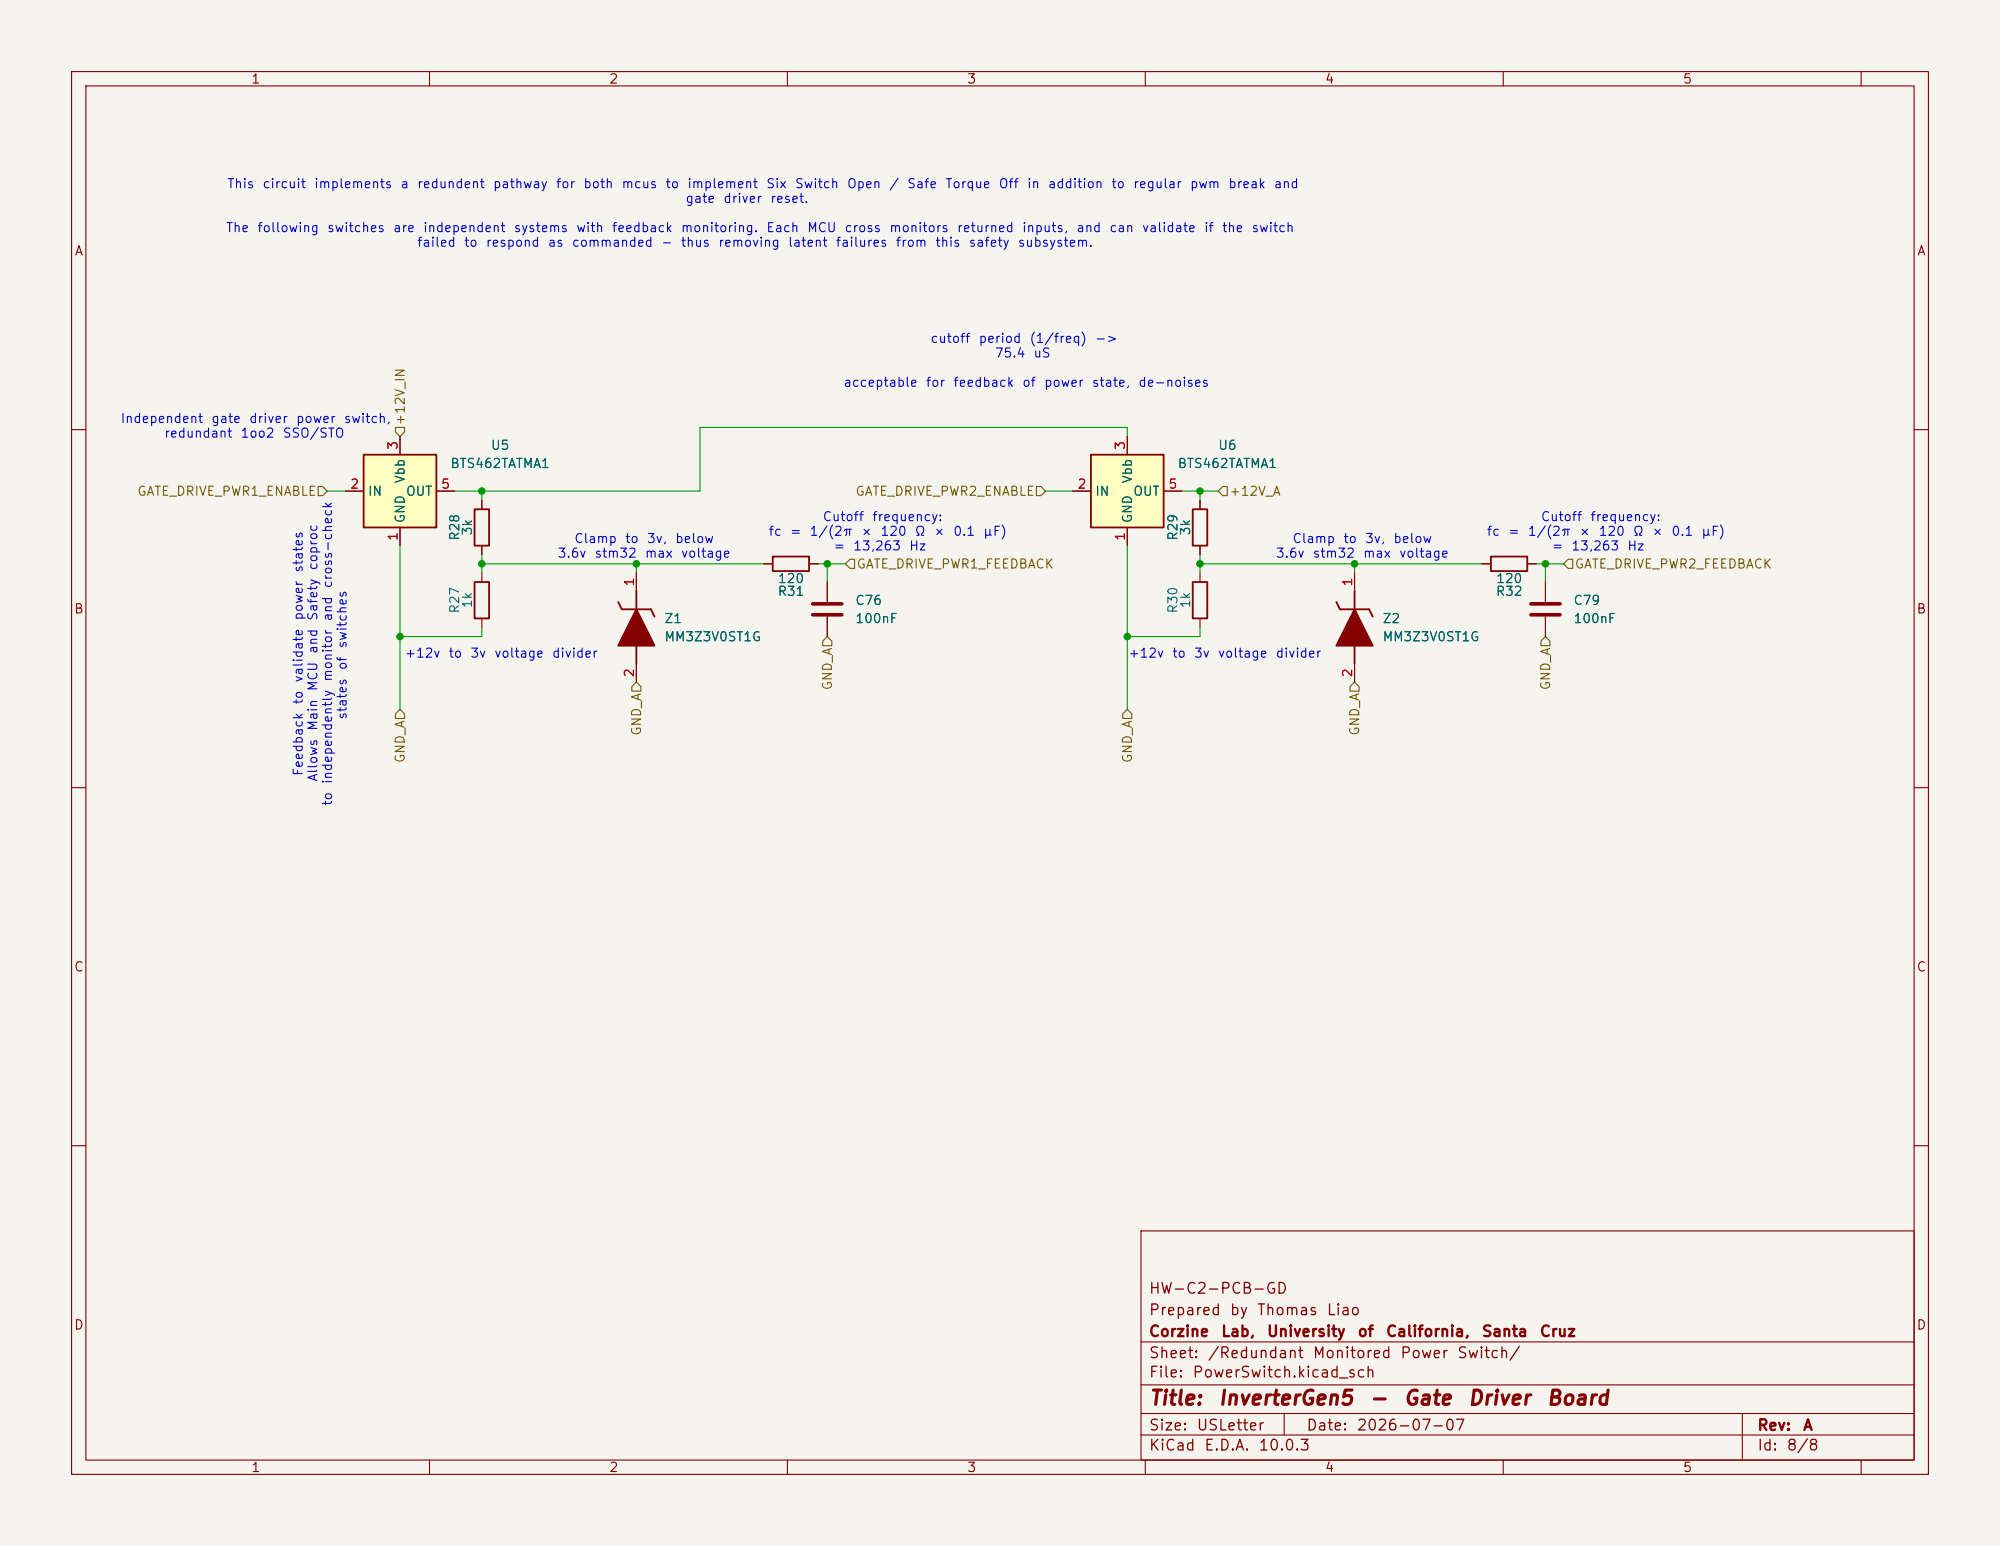
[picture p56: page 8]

3.6v stm32 max voltage +12v to 3v voltage divider This circuit implements a redundent pathway for both mcus to implement Six Switch Open / Safe Torque Off in addition to regular pwm break and
gate driver reset. The following switches are independent systems with feedback monitoring. Each MCU cross monitors returned inputs, and can validate if the switch

Independent gate driver power switch, redundant 1oo2 SSO/STO

Prepared by Thomas Liao
Corzine Lab, University of California, Santa Cruz
Sheet: /Redundant Monitored Power Switch/
File: PowerSwitch.kicad_sch
Title: InverterGen5 - Gate Driver Board

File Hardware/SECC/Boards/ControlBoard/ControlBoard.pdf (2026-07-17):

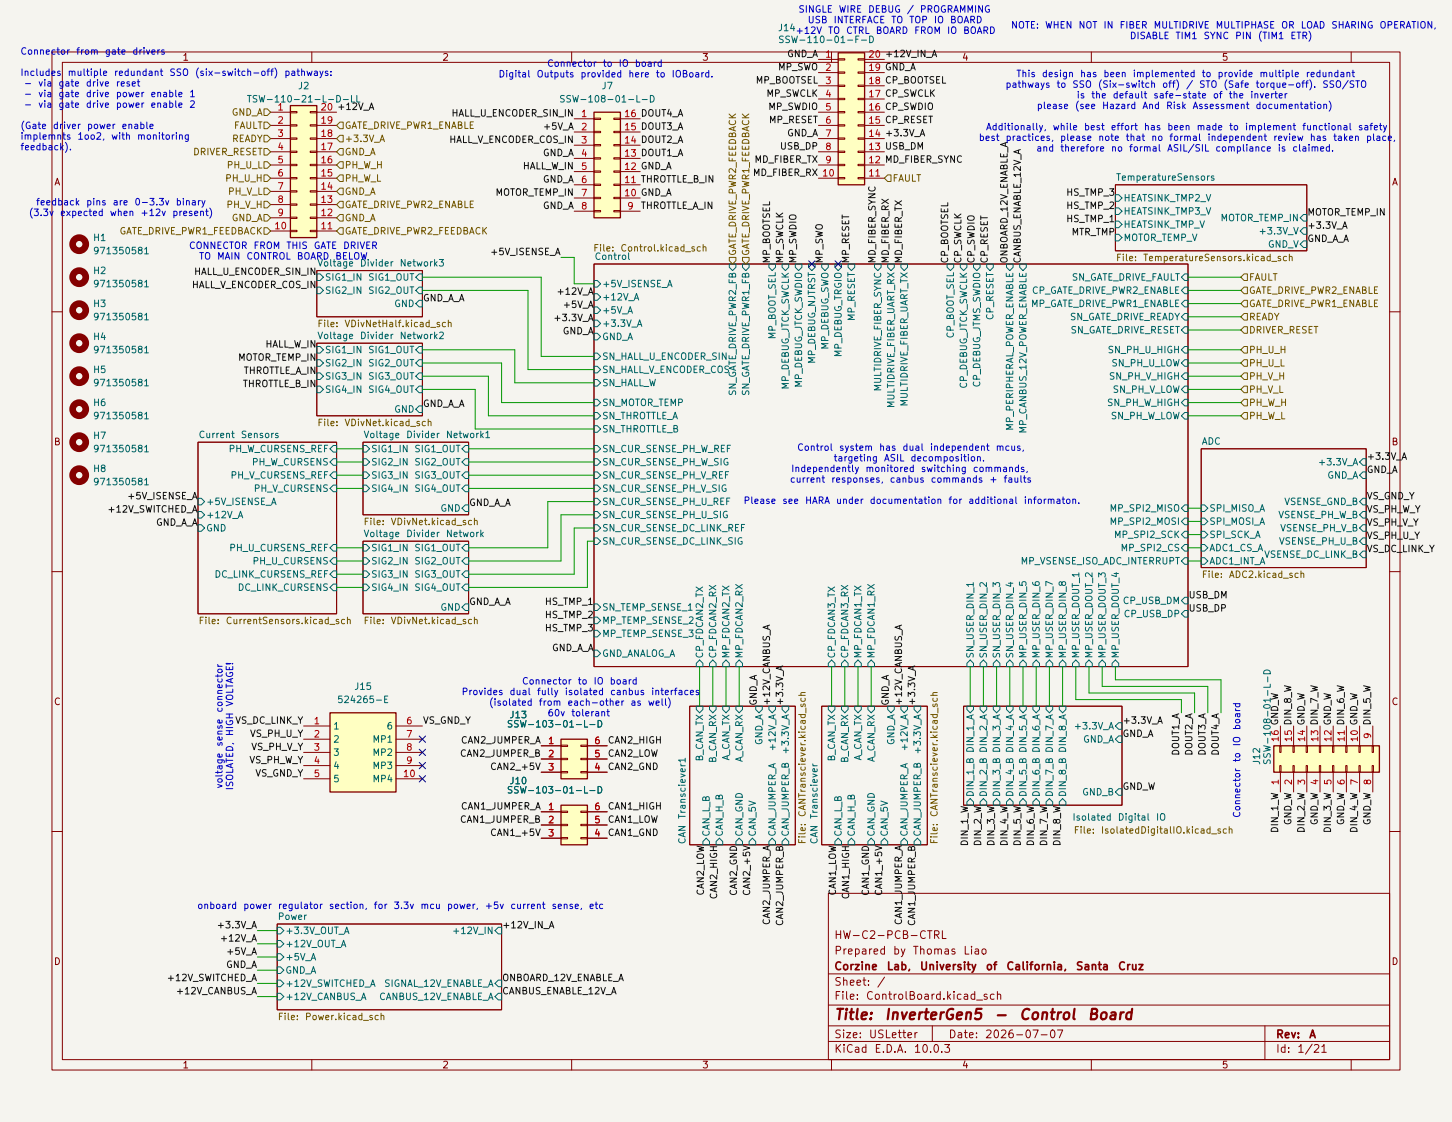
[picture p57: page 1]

Additionally, while best effort has been made to implement functional safety best practices, please note that no formal independent review has taken place, and therefore no formal ASIL/SIL compliance is claimed. NOTE: WHEN NOT IN FIBER MULTIDRIVE MULTIPHASE OR LOAD SHARING OPERATION, DISABLE TIM1 SYNC PIN (TIM1 ETR) Connector from gate drivers

Includes multiple redundant SSO (six-switch-off) pathways: - via gate drive reset - via gate drive power enable 1 - via gate drive power enable 2

This design has been implemented to provide multiple redundant pathways to SSO (Six-switch off) / STO (Safe torque-off). SSO/STO

is the default safe-state of the inverter please (see Hazard And Risk Assessment documentation)

(Gate driver power enable
implemnts 1oo2, with monitoring
feedback). feedback pins are 0-3.3v binary

TemperatureSensors File: TemperatureSensors.kicad_sch DC_LINK_CURSENS DC_LINK_CURSENS_REF GND

Independently monitored switching commands, current responses, canbus commands + faults Please see HARA under documentation for additional informaton. CONNECTOR FROM THIS GATE DRIVER
TO MAIN CONTROL BOARD BELOW
HALL_U_ENCODER_SIN_IN

PH_U_CURSENS PH_U_CURSENS_REF PH_V_CURSENS PH_V_CURSENS_REF PH_W_CURSENS PH_W_CURSENS_REF +12V_A +5V_ISENSE_A Current Sensors File: CurrentSensors.kicad_sch H2

onboard power regulator section, for 3.3v mcu power, +5v current sense, etc

Prepared by Thomas Liao
Corzine Lab, University of California, Santa Cruz
Sheet: /
File: ControlBoard.kicad_sch
Title: InverterGen5 - Control Board

Size: USLetter | Rev: A
KiCad E.D.A. 10.0.3 | Id: 1/21

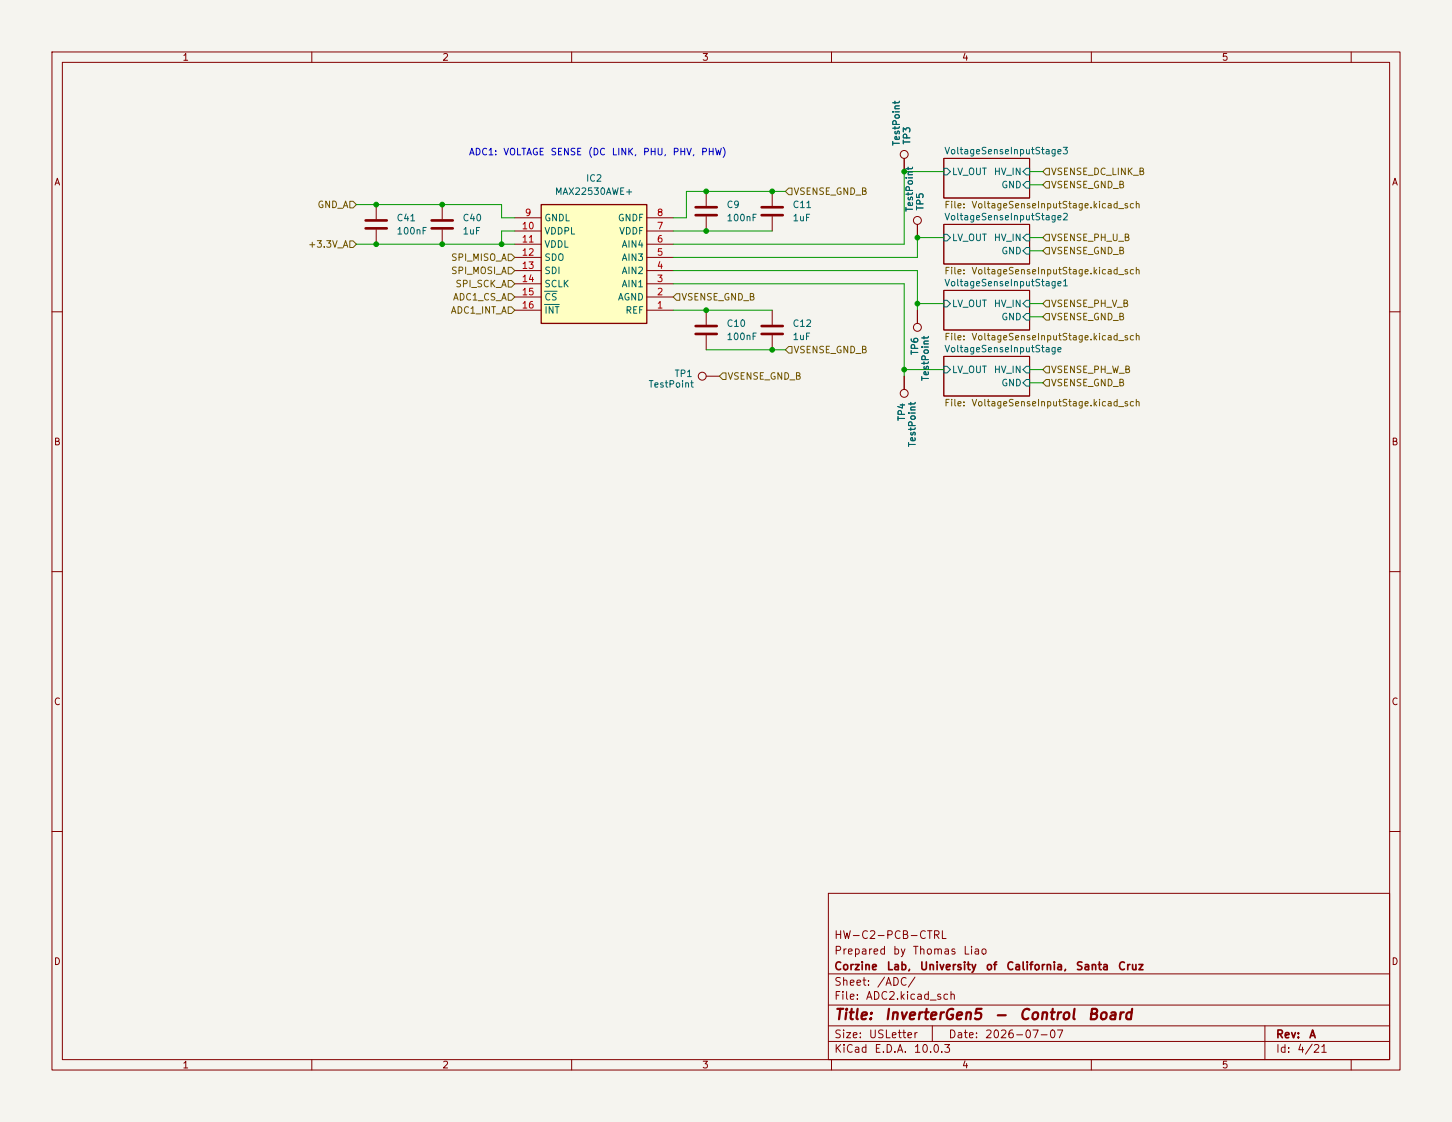
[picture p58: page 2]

HW-C2-PCB-CTRL
Prepared by Thomas Liao
Corzine Lab, University of California, Santa Cruz
Sheet: /ADC/
File: ADC2.kicad_sch
Title: InverterGen5 - Control Board

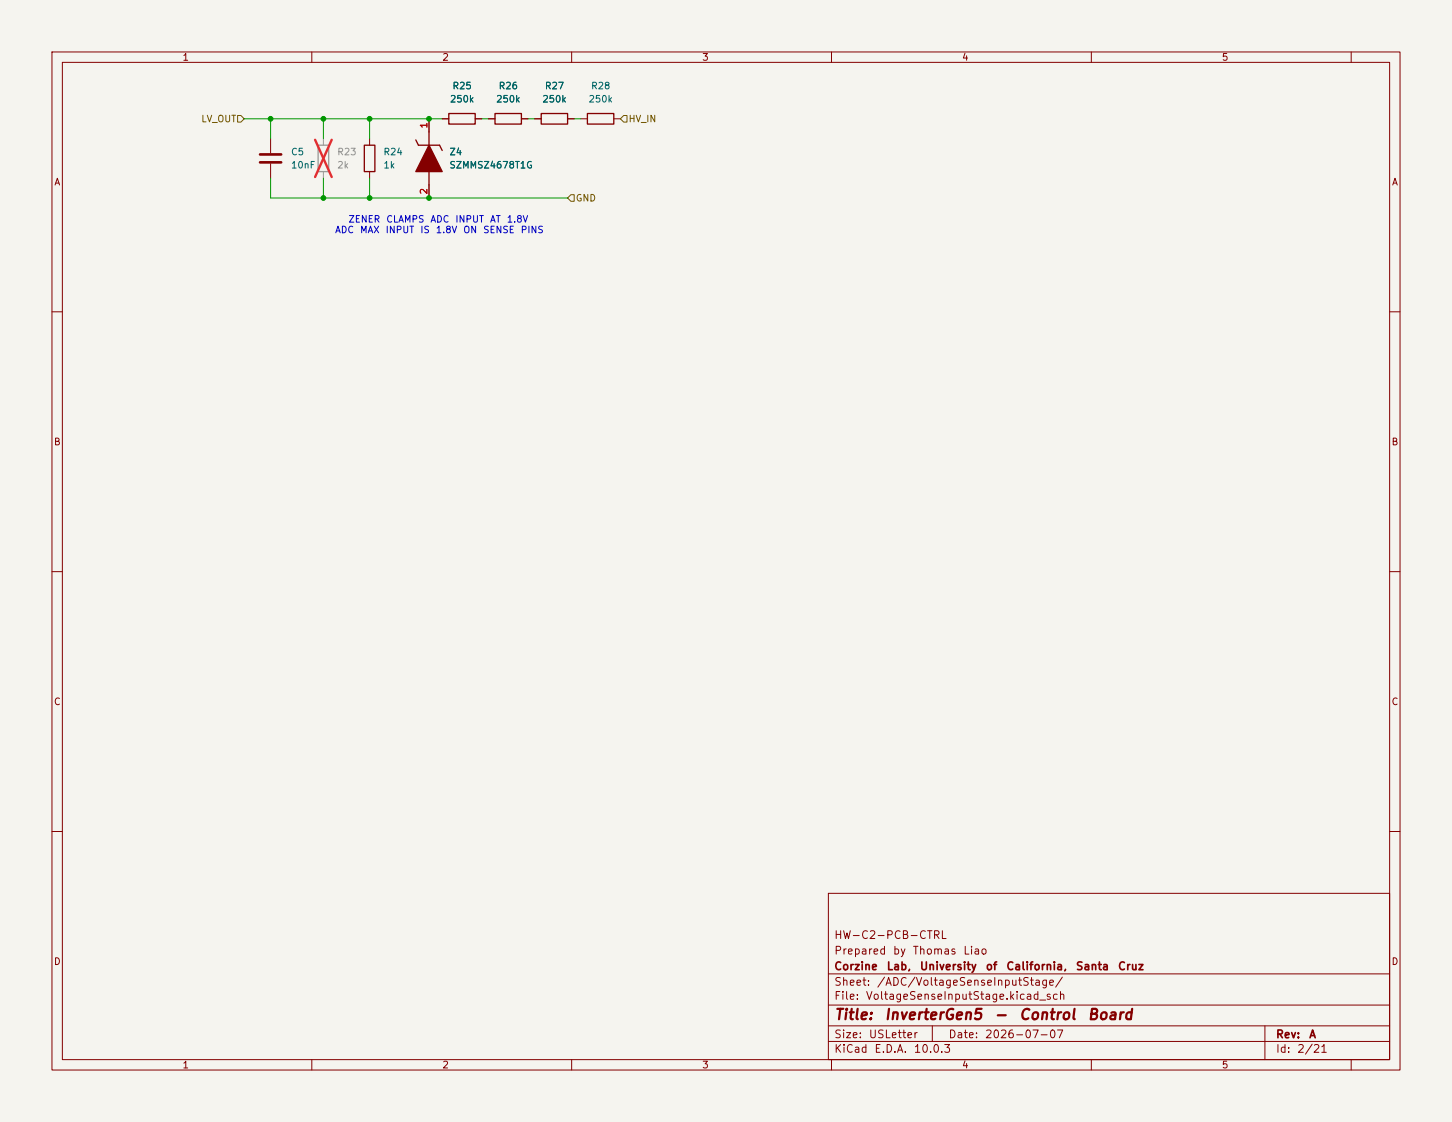
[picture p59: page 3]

ZENER CLAMPS ADC INPUT AT 1.8V
ADC MAX INPUT IS 1.8V ON SENSE PINS

HW-C2-PCB-CTRL
Prepared by Thomas Liao
Corzine Lab, University of California, Santa Cruz
Sheet: /ADC/VoltageSenseInputStage/
File: VoltageSenseInputStage.kicad_sch
Title: InverterGen5 - Control Board


ADC MAX INPUT IS 1.8V ON SENSE PINS R19

ZENER CLAMPS ADC INPUT AT 1.8V

HW-C2-PCB-CTRL
Prepared by Thomas Liao
Corzine Lab, University of California, Santa Cruz
Sheet: /ADC/VoltageSenseInputStage1/
File: VoltageSenseInputStage.kicad_sch
Title: InverterGen5 - Control Board


ZENER CLAMPS ADC INPUT AT 1.8V
ADC MAX INPUT IS 1.8V ON SENSE PINS

HW-C2-PCB-CTRL
Prepared by Thomas Liao
Corzine Lab, University of California, Santa Cruz
Sheet: /ADC/VoltageSenseInputStage2/
File: VoltageSenseInputStage.kicad_sch
Title: InverterGen5 - Control Board


ADC MAX INPUT IS 1.8V ON SENSE PINS R3

ZENER CLAMPS ADC INPUT AT 1.8V

HW-C2-PCB-CTRL
Prepared by Thomas Liao
Corzine Lab, University of California, Santa Cruz
Sheet: /ADC/VoltageSenseInputStage3/
File: VoltageSenseInputStage.kicad_sch
Title: InverterGen5 - Control Board


two can transcievers, allows safety coproc to snoop and interact with can traffic, if needed. provides redundant path to read and cross-check motor torque commands, if using canbus for torque cmd over throttle A/B inpts Close Jumper if terminating node

HW-C2-PCB-CTRL
Prepared by Thomas Liao
Corzine Lab, University of California, Santa Cruz
Sheet: /CAN Transciever1/
File: CANTransciever.kicad_sch
Title: InverterGen5 - Control Board


bus for Distributed Drive Communication (DDC). IO Board will need to be variant that has fiber in and out Enables power stage parallel operation or 6+ phase drives. PREFIX NAMING CONVENTION:
MP_ -> Main Processor
CP_ -> Co-Processor

reset switch, push to reset

Inter-mcu UART also runs challenge/response watchdog

desat + redundant adc current sense determined to be acceptable Safe Torque Off can be achieved within 100mS without OCP comparators Both STM MCUs have hw analog watchdogs that achieve the same function Safety coprocessor added as intent to target ASIL B(D) + ASIL B(D) Note: ASIL-B requires STM's SIL library which we cannot include here (propreitary) As such, this makes the approach a best-effort attempt. Additionally, no formal safety analysis by an independent agency has been performed.

For multidrive operation, hardware supports fiber ring

Power Supply Monitor File: PowerSupplyMonitor.kicad_sch +3.3V_A DC_LINK_CURRENT_REF_N

hw ocp not needed, see HARA for addt'l info
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

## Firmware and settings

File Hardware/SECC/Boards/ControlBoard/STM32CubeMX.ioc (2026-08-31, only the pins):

Mcu.UserName=STM32H723ZGTx
PA1.Signal=ETH_REF_CLK
PA10.Signal=USB_OTG_HS_ID
PA11.Signal=USB_OTG_HS_DM
PA12.Signal=USB_OTG_HS_DP
PA13(JTMS/SWDIO).Signal=DEBUG_JTMS-SWDIO
PA14(JTCK/SWCLK).Signal=DEBUG_JTCK-SWCLK
PA2.Signal=ETH_MDIO
PA6.GPIO_Label=CP_FEEDBACK
PA6.Signal=ADCx_INP3
PA7.Signal=ETH_CRS_DV
PA9.Signal=SPI2_SCK
PB0.GPIO_Label=CURSENS_A_REF
PB0.Signal=SharedAnalog_PB0
PB1.GPIO_Label=CURSENS_A_SIG
PB1.Signal=ADCx_INP5
PB12.Signal=FDCAN2_RX
PB13.Signal=ETH_TXD1
PB14.Signal=SPI2_MISO
PB15.Signal=SPI2_MOSI
PB3(JTDO/TRACESWO).Signal=SPI1_SCK
PB4(NJTRST).Signal=SPI1_MISO
PB5.Signal=SPI1_MOSI
PB6.Signal=FDCAN2_TX
PC1.Signal=ETH_MDC
PC11.GPIO_Label=GATE DRIVER FAULT
PC11.Signal=GPIO_Input
PC12.GPIO_Label=GATE DRIVER READY
PC12.Signal=GPIO_Input
PC4.Signal=ETH_RXD0
PC5.Signal=ETH_RXD1
PC7.Signal=DEBUG_TRGIO
PD1.GPIO_Label=VSENSE_ISO_ADC_INTERRUPT
PD1.Signal=GPIO_Input
PD2.GPIO_Label=SPI2_CS
PD2.Signal=GPIO_Output
PD5.GPIO_Label=GATE DRIVER RESET
PD5.Signal=GPIO_Output
PE1.GPIO_Label=DEBUG_ORANGE_LED
PE1.Signal=GPIO_Output
PE11.GPIO_Label=LIQUID_PUMP_PWM
PE11.Signal=S_TIM1_CH2
PE3.GPIO_Label=DEBUG_GREEN_LED
PE3.Signal=GPIO_Output
PE8.GPIO_Label=PWM_HIGH
PE8.Signal=TIM1_CH1N
PE9.GPIO_Label=PWM_LOW
PE9.Signal=S_TIM1_CH1
PF13.GPIO_Label=CURSENSE_B_SIG
PF13.Signal=ADC2_INP2
PF14.GPIO_Label=CURSENSE_B_REF
PF14.Signal=SharedAnalog_PF14
PF4.GPIO_Label=AIN_CABLE_TEMP
PF4.Signal=ADC3_INP9
PF7.Signal=FDCAN3_TX
PG10.Signal=FDCAN3_RX
PG11.Signal=ETH_TX_EN
PG13.Signal=ETH_TXD0
PG4.GPIO_Label=MAIN_CONTACTOR_OUT
PG4.Signal=GPIO_Output
PG6.GPIO_Label=PRECHARGE_CONTACTOR_OUT
PG6.Signal=GPIO_Output
PH0-OSC_IN.Signal=RCC_OSC_IN
PH1-OSC_OUT.Signal=RCC_OSC_OUT

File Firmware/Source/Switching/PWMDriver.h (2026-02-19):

/**
 ***********************************************************************************
 * @file    PWMDriver.h
 * @date    2026-02-15
 * @brief   RP2040 3-Phase PWM Driver with center-aligned (phase-correct) output.
 ***********************************************************************************
 */

#pragma once

#include "hardware/pwm.h"
#include <cstdint>


// AIDAN PLEASE MAKE THE PWMDRIVER SUPPORT THIS!
struct HardwareCommand {
    float SwitchingFrequency_Hz;
    float DutyPhU_unitless;
    float DutyPhV_unitless;
    float DutyPhW_unitless;
    
};


/**
 * @brief Handles generation of 3-phase complementary PWM signals for motor control.
 * 
 * This class manages the RP2040 PWM hardware to generate center-aligned PWM 
 * on three pairs of GPIO pins. It includes safety features such as emergency 
 * stop, hardware limits on duty cycle, and frequency configuration.
 */
class PWMDriver {
public:
    /**
     * @brief Configuration structure for PWM limits.
     */
    struct Config {
        float min_duty_percent = 2.0f; ///< Minimum duty cycle percentage (e.g., for bootstrap charging).
        float max_duty_percent = 98.0f; ///< Maximum duty cycle percentage (e.g., to prevent shoot-through).
    };

    /**
     * @brief Constructor.
     * @param cfg Configuration reference containing duty limits.
     */
    explicit PWMDriver(const Config& cfg);

    volatile uint32_t pwm_wrap_count_ = 0;  ///< Monotonic counter of PWM wrap events (used for timing).
    volatile uint32_t last_wrap_time_us_ = 0; ///< Timestamp of the last PWM wrap event in microseconds.
    bool isEnabled() const { return enabled_; }
    bool isEmergencyStopped() const { return emergency_stop_; }
    float getCarrierFrequency() const { return carrier_hz_; }

    /**
     * @brief Initializes the PWM hardware.
     * @param initial_carrier_hz The starting PWM frequency in Hz.
     */
    void init(float initial_carrier_hz);

    /**
     * @brief Updates the PWM carrier frequency.
     * @param hz New frequency in Hz.
     */
    void setCarrierFrequency(float hz);

    /**
     * @brief Sets the duty cycles for all three phases.
     * @param du Duty cycle for Phase U (0.0 to 1.0).
     * @param dv Duty cycle for Phase V (0.0 to 1.0).
     * @param dw Duty cycle for Phase W (0.0 to 1.0).
     */
    void setDutyCycles(float du, float dv, float dw);


    /**
    @brief NAUGHTY METHOD FIX THIS LATER ITS A VERY BAD BOY
    */
    void SetHardwareCommand(HardwareCommand _Cmd);

    void enable();
    void disable();

    void emergencyStop();
    void clearEmergency();

    /**
     * @brief Interrupt Service Routine handler called on PWM wrap.
     */
    void isrHandler();

    static PWMDriver* instance() { return instance_; }

private:
    /**
     * @brief Internal structure for timing calculations.
     */
    struct PwmTiming {
        float clk_div;
        uint16_t top;
    };

    static PWMDriver* instance_; ///< Singleton instance pointer.

    // ----- constants -----
    static constexpr float TWO_PI = 6.2831853071795864769f;

    static constexpr uint kPhaseCount = 3; ///< Number of motor phases.
    static constexpr uint kSlices[kPhaseCount] = {0, 1, 2}; ///< RP2040 PWM slice numbers used.

    struct PhasePins { uint a; uint b; }; ///< Structure holding high/low side pins for a phase.
    static PhasePins kPins[kPhaseCount]; ///< Pin mapping array {U_A, U_B}, {V_A, V_B}, etc.

    void recalcDutyLimits(); ///< Recalculates integer count limits based on current Top and percentage config.

    uint16_t computeTopFromCarrier(float carrier_hz) const;
    void chooseFixedDivider(float min_carrier_hz);

    static inline uint16_t clampDuty(uint16_t x, uint16_t lo, uint16_t hi) {
        return (x < lo) ? lo : (x > hi) ? hi : x;
    }

    static inline int16_t floatToQ15Clamp01(float x);

    /**
     * @brief Helper to set duty cycle on both channels of a slice (Complementary mode).
     * @param slice The PWM slice number.
     * @param level The compare level (duty cycle count).
     */
    inline void setSliceComplementary(uint slice, uint16_t level) {
        pwm_set_both_levels(slice, level, level);
    }

    void forceAllGpioLow();  ///< Forces all PWM GPIOs low as a safety measure.
    void restorePwmPins();   ///< Restores GPIO function to PWM after safety stop.

private:
    Config config_;
    
    float fixed_clk_div_ = 1.0f; ///< Calculated clock divider to ensure 16-bit counter range.
    bool enabled_ = false;
    bool emergency_stop_ = false;
    
    // Shadow registers updated by main thread, read by ISR
    volatile uint16_t manual_du_ = 0;
    volatile uint16_t manual_dv_ = 0;
    volatile uint16_t manual_dw_ = 0;

    // carrier / PWM timing
    float carrier_hz_ = 0.0f;
    float clk_div_ = 1.0f;
    uint16_t pwm_top_ = 0;

    // precomputed duty limits in counts
    uint16_t min_count_ = 0;
    uint16_t max_count_ = 0;
};

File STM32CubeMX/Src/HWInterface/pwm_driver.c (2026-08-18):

/**
  ******************************************************************************
  * @file    pwm_driver.c
  * @brief   TIM1 PWM driver wrapper implementation.
  ******************************************************************************
  */

#include "pwm_driver.h"
#include "tim.h"
#include "gate_driver.h"

#include <math.h>

static float clamp_duty(float x, float min, float max)
{
    if (x < min) return min;
    if (x > max) return max;
    return x;
}

void PWMDriver_Init(PWMDriver_t *drv, float carrier_hz, float min_duty_percent, float max_duty_percent)
{
    drv->min_duty_percent = min_duty_percent;
    drv->max_duty_percent = max_duty_percent;
    drv->carrier_hz = carrier_hz;
    drv->enabled = false;
    drv->emergency_stop = false;

    PWMDriver_SetCarrierFrequency(drv, carrier_hz);
    PWMDriver_SetDutyCycles(drv, 50.0f, 50.0f, 50.0f);
}

void PWMDriver_Enable(PWMDriver_t *drv)
{
    if (drv->emergency_stop) {
        return;
    }
    drv->enabled = true;
    PWM_Start();
}

void PWMDriver_Disable(PWMDriver_t *drv)
{
    drv->enabled = false;
    PWM_Stop();
}

void PWMDriver_EmergencyStop(PWMDriver_t *drv)
{
    drv->emergency_stop = true;
    drv->enabled = false;
    PWM_Stop();
    PWM_ClearFault();  /* clear break flag, but keep MOE low */
    GateDriver_ResetPulse();
}

void PWMDriver_ClearEmergency(PWMDriver_t *drv)
{
    drv->emergency_stop = false;
    PWM_ClearFault();
}

void PWMDriver_SetCarrierFrequency(PWMDriver_t *drv, float hz)
{
    if (hz <= 0.0f) {
        return;
    }
    drv->carrier_hz = hz;
    PWM_SetFrequency((uint32_t)hz);
}

void PWMDriver_SetDutyCycles(PWMDriver_t *drv, float du, float dv, float dw)
{
    du = clamp_duty(du, drv->min_duty_percent, drv->max_duty_percent);
    dv = clamp_duty(dv, drv->min_duty_percent, drv->max_duty_percent);
    dw = clamp_duty(dw, drv->min_duty_percent, drv->max_duty_percent);

    PWM_SetDutyCycle(0, du);
    PWM_SetDutyCycle(1, dv);
    PWM_SetDutyCycle(2, dw);
}

void PWMDriver_SetHardwareCommand(PWMDriver_t *drv, const HardwareCommand_t *cmd)
{
    PWMDriver_SetCarrierFrequency(drv, cmd->SwitchingFrequency_Hz);
    PWMDriver_SetDutyCycles(drv,
                            cmd->DutyPhU_unitless * 100.0f,
                            cmd->DutyPhV_unitless * 100.0f,
                            cmd->DutyPhW_unitless * 100.0f);
}

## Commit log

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2026-02-07 Update Silscreen for variants, fix gate driver and remove todo
    [ControlBoard-B_Cu.gbr, ControlBoard-B_Mask.gbr, ControlBoard-B_Paste.gbr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]
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2026-02-14 Revert "new bridge pwm mess"
    This reverts commit 33c83ea8a4795d46c291bee9741b9557976feb98.
    [PWMDriver.h]
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2026-02-17 maybe fix foc pid
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2026-02-18 reverse pid values
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2026-02-18 Fix reverse direction foc (still needs more loop tuning/move to PID), tidy PWMDriver
    [PWMDriver.h]
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2026-02-26 better dma stability (but still issues with longer FOC loop timing)
2026-02-26 fixed dma (most likely!)
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2026-05-19 fix spacing and coupling isssues on pcbs
    [ControlBoard.kicad_pcb, GateDriver.kicad_pcb]
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2026-06-06 led blink but reset issues
    [STM32CubeMX.ioc]
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2026-06-08 uart flash with mcp2221A reset and boot sel gpio
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2026-06-09 TIGHTened timings
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2026-06-20 refactor(STM32CubeMX): isolate application code, extract PWM driver
    - Replace main.c with minimal CubeMX stub that calls InverterMain_Run()
    - Move custom hardware drivers into Src/Inverter/Drivers/
    - Extract all PWM/SPWM logic from tim.c into Src/Inverter/Drivers/PWM/
    - Update CMakeLists.txt for C++, inverter sources, and PWM include path
    - Regenerate CubeMX with restored ADC/FDCAN/TIM1 hardware configuration
    - Set TIM1 deadtime to 194 and PWM GPIO speed to very high
    [STM32CubeMX.ioc]
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2026-06-20 fix(telemetry): reduce definition re-announce rate to 1 Hz
    The ground tool was seeing ~20 Hz RX because updateSensors()
    was sending both definition frames and data frames every 100 ms.
    Definitions now re-announce once per second, so the observed
    RX rate matches the configured 10 Hz data rate.
2026-06-20 telemetry: switch to DMA, fix 1 Hz on-time logging, add 100 Hz sine test
    - Move telemetry TX ring buffer to RAM_D1 (AXI SRAM) so DMA1 can access it;
    DTCMRAM is CPU-only on STM32H7, which caused zero output with DMA.
    - Replace blocking HAL_UART_Transmit with ring-buffer + HAL_UART_Transmit_DMA.
    - Add HAL_UART_TxCpltCallback to chain the next DMA chunk.
    - Revert define re-announce rate to 10 Hz.
    - Update on-time logger only once per second instead of every telemetry frame.
    - Add 1 Hz test_sine value sampled at 100 Hz.
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2026-06-21 big error but kinda working adc with tim
2026-06-21 fixed current sense drift bug - caused by cdr packing bug with dma
2026-06-21 broken encoder with non entered low noise currentsense
2026-06-21 fixed encoder
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2026-06-23 Revert "more calibration time"
    This reverts commit aa27028b14ddeeeff349441c03d19d0a57b775f9.
2026-06-23 Fix current-sense zero offset by calibrating after gate-driver power-up
    The phase-current zero offset (especially phase U) persisted after boot
    because the initial calibration ran before the gate-driver isolated
    power rail was enabled. Enabling GATE_DRIVER_POWER_ENABLE shifts the
    sensor's zero-current point, so the stored offsets became wrong.
    Changes:
    - Calibrate current-sensor offsets in OpenLoopController::init() after
    the gate-driver power rail is enabled and stable.
    - Add a 'cal' shell command and auto-recalibrate on motor stop.
    - Add a 'raw' command to inspect raw ADC counts and offsets.
    - Increase current-sense moving-average filter length to 32 taps.
    - Remove the long warm-up dela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
2026-06-26 fault manager and fixed current sense
2026-06-26 fixed startup power transient and dip
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2026-06-29 Revert "current state - appears working?"
    This reverts commit e928360c1f541a730ea782ac3a06e1c27c8a8629.
2026-06-29 broken calibration
2026-06-29 FIED PIN MAPPING BUG!!!
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2026-07-01 fixed fault clear switching turning on
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2026-07-10 fix power monitor ic connections
    [Control.kicad_sch, ControlBoard.kicad_pcb, MainMCU.kicad_sch]
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2026-07-11 Fix wrong deletion error
    [ADC.kicad_sch, ADC2.kicad_sch]
2026-07-12 Update Gate Driver Board, New Connector, New Desat Diode, 1oo2 SSO Pathway
    [GateDriver.kicad_pcb, GateDriver.kicad_sch, GateDriver.step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]
2026-07-12 Updated Gate Driver, Fixed Vsense connector on Cotnrol Board
    [524265-E.stp, ADC2.kicad_sch, ControlBoard.kicad_pcb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]
2026-07-12 Finished IO Board, Added Socket For Fiber DDC IO Module, Updated Mechanical Drawings
    [IOBoard.kicad_pcb, IOBoard.kicad_sch, IOBoard.step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]
2026-07-12 Fix FOC calibration handling and add forced-angle diagnostic
    - Persist encoder sign detected by motorcal into MotorCalibration and
    telemetry (was lost, forcing wrong sign after calibration)
    - Fix encoder-offset formula for sign=+1 in EncoderOffsetCalibrator
    (field_mech - encoder_raw, matching the FOC angle convention)
    - Reset stale runtime offset adjustment when a new motorcal completes;
    previously the old delta was silently added on top of the fresh offset
    - Trip EncoderTimeout and safe-stop if the encoder stream stalls during
    FOC (frozen Park angle would lock the rotor while currents regulate)
    - Add 'foc forced <elec_hz>' diagnostic: full current loop with the Park
    angle driven b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
2026-07-13 Powerstage intermediate rework
    [91502A183_Blue-Dyed Zinc-Plated Alloy Steel Socket Head Screw.STEP, 94669A190_Aluminum Unthreaded Spacer.STEP, 94669A196_Aluminum Unthreaded Spacer.STEP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]
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2026-07-13 Update Mechanical Model, Fix Interference Issues
    [9774030592R.stp, DCBusCapacitorBoard.kicad_pcb, DCBusCapacitorBoard.step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]
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2026-07-14 fix schematic to aec-q100 gate driver p/n
    [SingleChannelDriver.kicad_sch]
2026-07-14 docs: overhaul README — verified against Chassis 2 Rev G schematics and current doc set
    - Ground-truth correction pass via schematic swarm review (NCV57100 gate
    drivers, 3x CM600DY-24T modules, 19.8 mF/200 V DC link bank, ISO1042BDWVR,
    TPS389006-Q1 rail supervisor, ISO1212 DINs, Cincon on IO board)
    - New DC Link section incl. aluminium heat-spreader plate cooling
    - Doc metadata synced: HARA v4.0/108p, TARA v1.1/19p, SWAD v1.4/45p,
    Manual v2.3/29p; 99 fault-injection tests (50/19/18/12)
    - Review-swarm fixes: DRIVER_RESET turn-off wording, 800 V upgrade path
    framing, divider/accuracy qualifications, bleeder warning, SSO pathway
    notes, SIL 3/ASIL D phrasing per TI
2026-07-14 docs: consulting-company consistency pass — HARA v4.1, SWAD v1.5, TARA v1.2, Manual v2.4 sync
    - Add CT-09 CAN DoS / heartbeat timeout and align TARA counts
    - Correct HARA SSO pathway enumeration, 2oo3 voting, ASIL parentheticals, and table numbering
    - Rebuild SWAD FSR-to-module traceability and fault-classification mappings to HARA v4.1
    - Fix Manual capacitor type, isolation ratings, modulation list, and 1001:1 voltage-sensing spec
    - Correct DC-link thermal-analysis initial-concepts and sensitivity-table arithmetic
    - Add UCS2W680MHD 68 µF / 450 V capacitor-only upgrade note with 5 mm standoff change
2026-07-14 fix(Hardware/Chassis2): gate driver AEC-Q100 MPN and precharge <2 A note
    - Update GateDriver schematic/PDF to AEC-Q100 gate driver part number
    - Update IOBoard schematic/PDF precharge note to stay below 2 A input fuse limit
    [IOBoard.kicad_sch, SingleChannelDriver.kicad_sch]
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2026-07-15 Update docuemntation - fix capacitor discharge info
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2026-07-16 Update all repo structure, add bom tool, part cost tools, fabrication outputs, part numbering, etc, partially finished final fab files
    [90225A102_18-8 Stainless Steel Square Nut.STEP, 91290A165_Black-Oxide Alloy Steel Socket Head Screw.STEP, 91292A112_18-8 Stainless Steel Socket Head Screw.STEP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]
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2026-07-16 Fix stale model
    [ControlBoard.step]
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2026-07-16 Fix internal project references after harness rename, update render
    [GDVSHarness.kicad_pcb, GDVSHarness.kicad_sch]
2026-07-16 Add TempSense harness, support KiCad 10 schematic BOM exports
    - Parser accepts the KiCad 10 symbol-fields export (Reference,Qty,Value,
    DNP, Exclude from BOM) alongside board Fab CSVs; DNP/excluded skipped
    - TempSenseHarness registered as HW-C2-WH-TSIGBT-A
    - Prices: 3M156058-ND thermal pad 46.98, CM600DY-24T IGBT 323.50
    [TempSenseHarness.kicad_pcb, TempSenseHarness.kicad_sch]
2026-07-17 Wire harness BOMs from KiCad, board BOM re-exports, tool follows new layouts
    - Four harnesses (GDVS, TSIGBT x2, CS x4, TSBCM) with per-chassis Qty
    - Board BOMs move to project dirs; discovery prefers root CSV, strips
    library prefixes from footprints, reads KiCad 10 exports
    - Mech list down to chassis hardware; IGBT moved to Mouser vendor
    - Harness parts leave MechanicalBOM.txt (455-1135-1-ND=SXH-001T-P0.6,
    BC5011CT-ND stray cap, TSW/LA37S600/0022011042/0008500113)
    [CapacitorTempSenseHarness.kicad_sch, ControlBoard.kicad_sch, CurrentSenseHarness.kicad_sch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]
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2026-07-17 DigiKey/Mouser price imports, importer fixes, DigiKey housing source
    - New digikey importer (BOM-tool xlsx/csv export)
    - Mouser importer: resolve rows uploaded with only manufacturer PNs
    (57 lines recovered), back-fill resolved PNs into the part DB,
    reject NaN prices
    - fab: board BOM CSV check follows project-dir convention
    - 544958-E housing: order as digikey 544959-E @ 2.68
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2026-07-17 HARA-style release PDF, STEP previews, board 3D renders, assembly iBOM
    - PDF restyled to Docs/HARA.pdf format (A4, Liberation Sans, green,
    swoosh cover, contents page)
    - Fab part previews rendered from STEP (cadquery + matplotlib, no GL)
    - Board dividers get fresh kicad-cli 3D renders (top+bottom)
    - FabricationData/Assembly/<Board>.html interactive iBOM per board
    - bom.py re-execs into .venv (sys.prefix check) so deps always resolve
    - requirements: + cadquery, matplotlib, InteractiveHtmlBom
2026-07-17 regen pipeline, solid STEP renders, larger board images
    - regen: per-board BOM CSV, gerbers+drill, board STEP, DRC report,
    harness BOMs, then generate (kicad-cli sch/pcb exports)
    - STEP previews: manual per-face lighting, no mesh seams, true aspect
    - Board divider renders stacked full-width
    [ControlBoard-B_Courtyard.gbr, ControlBoard-B_Cu (Signal).gbl, ControlBoard-B_Fab.gbr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]
2026-07-17 Design documents as parts, DRC in package, harness rev/qty, doc accuracy pass
    - docgen: Docs/*.html/*.md compile (weasyprint) into the release package
    with document IPNs (HW-C2-DOC-*) — 323-page design package
    - DRC errors-only; per-board DRC summary pages in the PDF (all clean)
    - Fabrication table shows harness qty and revision
    - Accuracy review of HARA/TARA/SWAD/Manual/README (CAN jumpers, FRAM
    owner, UVLO swap, Rev A, H723 RAM, 100ms, TARA CT-09)
2026-07-17 Standardize docs on Markdown template, thermal 3.18mm recalc, regen fab cleanup
    - All Docs/ converted to one Markdown->PDF pipeline (docgen: cover,
    auto-TOC with page numbers, footers); HTML sources retired
    - Thermal analysis: plate corrected to 3.18mm, all dependent values
    recomputed; LaTeX converted to Unicode
    - README: SSO within 1 PWM period, discharge as planned feature
    - regen: clean stale fab outputs before gerber/drill export
    - Stale Boards/BOMs/ removed
    [Combined.csv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]
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2026-07-17 Polish release output: drop empty assembly price table, fix part renders, friendly titles
    - In-House Assembly (unpriced) removed from PDF order summary
    - Fab part previews: orthographic projection (no distortion), bigger
    display, frame fit to part shape
    - Board/harness titles come from schematic title blocks
    ('IGBT Temperature Wiring Harness' not TEMPSENSEHARNESS)
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2026-07-17 Rename Open Inverter Platform to InverterGen5, schematic PDF export, tidy variants
    - Title blocks renamed to InverterGen5 in all harness schematics
    - regen now re-exports schematic PDFs for boards and harnesses too
    - Spares variants live under FabricationData/BOMs/Variants/
    [CapacitorTempSenseHarness.kicad_sch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]
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2026-07-17 Two-unit build: SCS cart prices imported, qty scaling bugs fixed
    - SendCutSend prices updated from cart (BSP 144.46, CHSP 24.67,
    PBB 17.03, DCLBB 45.12) — report subtotal matches cart at 620.92
    - info.txt now wins over stale cache for SendCutSend pricing
    - Vendor CSVs scale with --qty (were stuck at 1-unit quantities)
    - Spares variants scale with build qty
    [Consolidated_BOM.csv, assembly_bom.csv, digikey_bom.csv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]
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2026-07-17 Labels tool, composite board views, InverterGen5 C2 branding, even render resolution
    - Labels.pdf: HV warning labels, chassis ID, per-assembly labels (label cmd)
    - Board sections add composite front/back views (PCB-viewer look, mirrored
    back) and layer plots now carry the drawing sheet with true plot scale
    - Branding standardized to InverterGen5 C2 (cover, footer, labels)
    - STEP previews render at even resolution regardless of part aspect
    - Fab part titles from info.txt PartName; ALL-CAPS handling fixed
    [ADC2.kicad_sch, CANTransciever.kicad_sch, Control.kicad_sch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]
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2026-07-20 Flash via InverterClient HTTP API when running; fix UART bootloader sync
    - build_flash_uart.sh: if the InverterClientImGui app is up, POST the
    binary to its HTTP flash server (localhost:18080) and poll
    /flash/status, so the client can stay open during flashes; fall back
    to direct flash_uart.py otherwise. Override URL with
    INVERTER_CLIENT_FLASH_URL.
    - flash_uart.py: drain serial again AFTER entering the ROM bootloader
    (app telemetry spam buffered in the MCP2221A/host drowned the
    bootloader sync ACK); bigger drain read
    - reminder.md: document the client-API flash path and the mandatory
    post-bootloader drain
2026-07-20 Fix current telemetry starving when FOC runs
    PhaseCurrentADC::sample() is consume-once: FOC's onPwmPeriod() eats the
    freshness flag at the 2.5 kHz control rate, so the 100 Hz telemetry
    path in CurrentSensorTest_RunOnce lost the race ~30% of the time and
    republished stale values whenever FOC was active (even at iq=0).
    Add latest(), a non-destructive read for telemetry/logging consumers,
    and use it in CurrentSensorTest_RunOnce. sample() keeps its
    consume-once semantics for the control loop.
2026-07-20 Motor config persistence in F-RAM + SPI4 read reliability fix
    FramStore: generic fixed-slot record store on the CY15B102Q (magic /
    node id / version / length / CRC32 per 256-byte slot, node id 1..1023).
    Intended home for future persistent nodes beyond the motor config.
    MotorConfigStore: typed motor config (MotorType enum for future
    induction/synrel/brushed/... machines, poles, encoder cycles/offset/
    sign, per-phase resistance, reserved flux linkage and Ld/Lq, PI kp/ki).
    - Boot auto-loads and applies it (FOC can run without re-calibration)
    - motorcal auto-saves on completion
    - 'motorcfg dump/save/load/clear/set/type' shell command
    Also:
    - Fix PoleCalibrator::isActive() not excluding FAIL, w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
    [STM32CubeMX.ioc]
2026-07-20 Persist learned encoder bounds in motor config (schema v2)
    Motorcal seeds the encoder sin/cos amplitude bounds dynamically as the
    rotor turns, but they were RAM-only: after a reboot the angle was
    normalized against the wide hardcoded fallback caps until ~1 rev of
    rotation. The resulting 2nd-harmonic angle error can detent-lock the
    rotor when FOC starts ('hiccup, then doesn't turn').
    - MotorConfigData v2 appends enc sin/cos min/max; FramStore::load now
    accepts shorter older-version payloads and zero-fills the tail, so
    v1 records keep working
    - capture() stores the active learned bounds (keeps previous ones if
    not yet learned this boot); applyToRuntime() seeds them via
    encoderADC().se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
2026-07-20 Remove constant-switching-frequency assumptions
    The switching frequency and modulation scheme are user-defined runtime
    settings, not constants:
    - FocControlManager: recompute the control-loop dt whenever the live
    update frequency changes (checked each update()); previously it was
    latched once at FOC start and went stale after any PWM_SetFrequency
    - InductanceCalibrator: pin a known switching frequency for the
    measurement (CAL_SWITCHING_HZ) and restore the user's setting on
    every exit path (done/fail/stop)
    - EncoderADC: derive the RPM sample rate from the actual TIM2 trigger
    configuration instead of a hardcoded 10 kHz constant
    Documented as a standing rule in reminder.md.
2026-07-21 Bus-voltage robustness: current clamps for open-loop cal phases (60V)
    At 60 V the open-loop calibration phases drew 2x the current (460 A
    measured, 600+ A at 120 V projected):
    - OpenLoopController gains a continuous current clamp
    (updateCurrentClamp): throttles applied modulation whenever phase
    current exceeds rclimit (default 250 A, was 600 A) and recovers
    slowly - bounds current at ANY bus voltage, in and out of ramps
    - CurrentLimitedRamp throttles the same way (floored at 0.5x target)
    instead of pausing-then-aborting, so offset rotation continues at
    the limit instead of failing
    - Rotation duty is now breakaway x1.0 (was x1.3 margin): measured at
    60 V the min-follow level is ~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
2026-07-21 DC-link current sensor + input power/energy telemetry
    New DcLinkCurrentSensor: reads DC_LINK_CURSENS (ADC1_INP2 signal /
    ADC1_INP6 reference, same LA37S600 differential scheme as the phase
    sensors) with sequential single polled conversions from the main loop.
    Logs dcl_i_a, dcl_p_w (= vdc_v * dcl_i_a) and dcl_e_wh (integrated
    energy) at 40 Hz; dclzero shell command re-captures the zero offset
    and resets the energy counter.
    Implementation note: must not use HAL_ADC_Stop or a full HAL_ADC_Init
    here - both kill the live injected phase-current stream (found out the
    hard way: frozen phase telemetry + dead shell). Sequential single
    conversions with per-conversion rank reconfiguration are safe.
2026-07-21 Revert injected DC-link current ranks; disable DCL reads for now
    The 4-rank injected sequence (4 on ADC1 vs 2 on ADC2 in dual
    simultaneous mode) degraded phase-current quality - the length
    mismatch broke the phase refs. Reverted; phase sensors are back to
    normal. DcLinkCurrentSensor::update() disabled until DC-link current
    gets a sampling path that doesn't fight the phase path.
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2026-07-21 Windowed RPM estimator: kills switching-EMI speed jitter
    The per-sample angle-delta RPM estimator multiplied raw angle noise by
    the full 10 kHz sample rate (x1666), so ~0.5 deg of encoder noise at
    higher switching frequencies showed up as +/-80 RPM of fake jitter.
    Estimate speed from the angle delta over a 40-sample (~4 ms) window
    plus a heavier output EMA instead: 2.5 kHz now reads +/-0.3 RPM and
    6 kHz +/-9 RPM (was +/-80). The FOC frame keeps the unfiltered angle,
    so there is no commutation lag.
2026-07-21 Fix encoder speed-estimate time base (self-calibrate from measured ISR rate)
    The estimator assumed a 10 kHz sample rate from an incorrect 'APB1 =
    137.5 MHz' comment; the measured encoder DMA rate is ~17.5 kHz, so
    rpm_mech under-read badly (725 vs 1095 RPM actual). The estimator now
    self-calibrates m_sample_hz from a live ISR-rate counter (enc_isr_hz)
    each second. Verified against a laser tach: 1098 reported vs 1095
    measured at 2 kHz switching.
    Also adds the windowed RPM fix from the previous commit's verification
    (6 kHz sd ~11 RPM, 2.5 kHz sd ~0.3 RPM).
2026-07-22 Align FOC update rate with ADC sample rate and reduce oversampling
    - PWM_EnableFocMode now uses RCR=1 so the FOC ISR runs once per PWM
    period, matching the once-per-period TIM1 CH4 / OC4REF ADC trigger.
    This eliminates the stale/missed current samples seen above ~2 kHz.
    - Reduced injected oversampling from 16x to 8x to fit the sequence
    comfortably inside one PWM period at higher switching frequencies
    (~33 us vs ~65 us conversion time).
    Builds cleanly.
2026-07-22 Revert "Align FOC update rate with ADC sample rate and reduce oversampling"
    This reverts commit e78e86e606c5ff728309848a76296007db5f95be.
2026-07-22 Reduce phase-current ADC oversampling from 16x to 8x
    Keeps dual-update FOC (RCR=0) unchanged. The faster injected-sequence
    conversion time (~33 us vs ~65 us) lets the ADC finish before the next
    FOC cycle at higher switching frequencies, reducing stale/missed samples
    without altering the control-loop bandwidth.
    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
2026-08-17 Updated mechanical model; regenerated Fab artifacts; printed-part qty fixes
    - InverterMechanical.FCStd model update
    - Re-extracted STEP models, holes.json, model_parts.json,
    mcmaster_model.json via freecadcmd; re-rendered info.png/info-back.png
    via headless Blender
    - MechanicalBOM.txt: McMaster 6926K56 qty 3 -> 5 (model merge)
    - Added info.txt for HW-C2-DCLSPCR-PRINTED-A (Qty=6 per model) and
    HW-C2-SHELL-PRINTED-A (Qty=1) so BOM quantities match the model
    [HW-C2-BSP-A.step, HW-C2-CHSP-A.step, HW-C2-DCLBB-A.step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]
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2026-08-23 chassis2: busbar/spacer/sensor-access mechanical updates, add chassis0 model
    - access to back of current sensors (areas marked with x)
    - heatspreader plate to capacitor clearance
    - phase bus bar end-user lug retention screw hole clearances
    - dc link bus bar end-user lug retention screw holes added
    - spacers between dc bulk cap board and al plate to prevent board
    flexing during tightening
    - fixed dc link module holders/spacers and interference with film caps,
    made captive to hold spacers tighter
    - holes for thermocouple in dc link bulk cap alu plate
    - swapped steel black iron screws for stainless steel m5, 90deg
    countersink
    - added sloped guide channels on dc link and phase bus bars to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
    [InverterMechanical.FCStd]
2026-08-23 c2 mechanical rev bump: CHSP-B, DCLMH-200-PRINTED-B, DCLSPCR-PRINTED-B
    - CHSP-A -> CHSP-B: 90 deg countersink spec fix, plate now 6.35 mm
    (was 3.17 mm) for better heat dissipation and cap height clearance
    - DCLMH-200-PRINTED-A -> -B: captive holder fix, no longer interferes
    with film caps
    - DCLSPCR-PRINTED-A -> -B: redesigned to fit, conjoined sets (qty 3
    instead of 6), holds aluminium current-carrying elements tightly
    - new HW-C2-DCLMH-200-SPCR-PRINTED-A x6: spacers between dc link bulk
    cap board and aluminium heatspreader plate, prevent board flexing
    during tightening
    - new HW-C2-THRMLPD-STNCL-A: 3D-printed PLA stencil for tracing/cutting
    the capacitor heatspreader thermal pad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
    [HW-C2-BSP-A.step, HW-C2-CHSP-A.step, HW-C2-CHSP-A.stl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]
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2026-08-25 Fix Current sensor Clearance Issue
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2026-08-29 Add build-variant support to BOMManager + C2 450V variant
    - variants.yaml per chassis: exclude/add/setqty rules applied to parsed
    BOM items; generate builds all declared variants by default, writes
    Builds/<variant>/, Variant_Comparison.md and variants.json manifest
    - 450v variant for Chassis2: UCS2W680MHD cap swap, 250-450V holder and
    cap spacer (geometry in InverterMechanical.FCStd), 94669A196->94669A193
    standoffs, extra M6 copper washers
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2026-08-30 C2-DCDC-A: 15 kW DC/DC converter build variant (450 V class)
    - new dcdc build variant in Hardware/Chassis2/variants.yaml: base C2 power
    stage + 450 V cap-bank swap (same rules as 450v) plus the DC/DC module
    extras from Mechanical/DC-DC-Module.FCStd
    - extras: 2x Hammond 195C100 DC filter chokes (1 mH, 100 A), 2x Boyd
    416201U00000G 305 mm 6-pass cold plates, 1x TDK B25645A1328K003
    3.21 mF/1 kV DC-link film cap, frame/cabinet hardware (rivet nuts,
    fasteners, handles, lid screws, warning labels)
    - new fab parts, STEP/STL/holes.json/renders exported via freecadcmd +
    headless Blender: HW-C2-FR-CLPHLD-A coldplate holder bracket,
    HW-C2-FR-BSP-A frame base plates x2, HW-C3-FR-CSP-A corn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
    [Cabinet-Cover-410mm.FCStd, Chassis-Common.FCStd, Consolidated_BOM.csv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]
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2026-08-31 Fix sendcutsend mfg issues
    [DC-DC-Module.FCStd]
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2026-09-14 Fix tolerances for bus bars, spacers
2026-09-15 Fix bus bar nut depth
